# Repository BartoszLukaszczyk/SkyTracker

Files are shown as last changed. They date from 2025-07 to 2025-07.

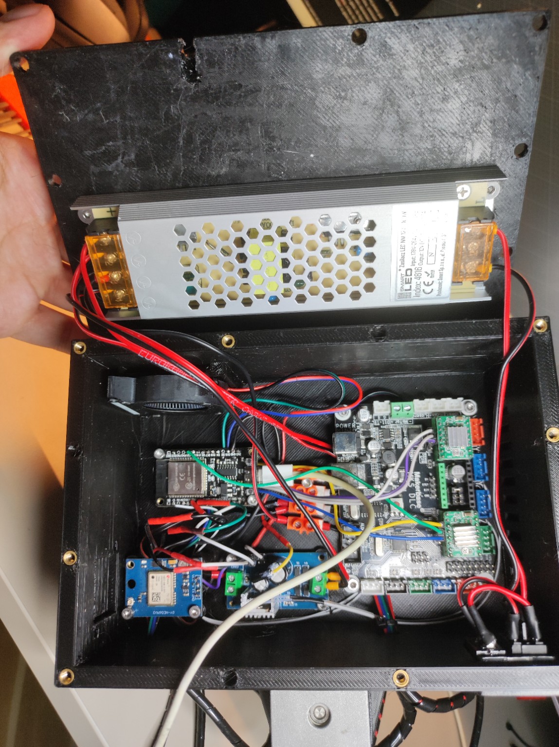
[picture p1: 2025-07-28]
images/electronics overview.jpg

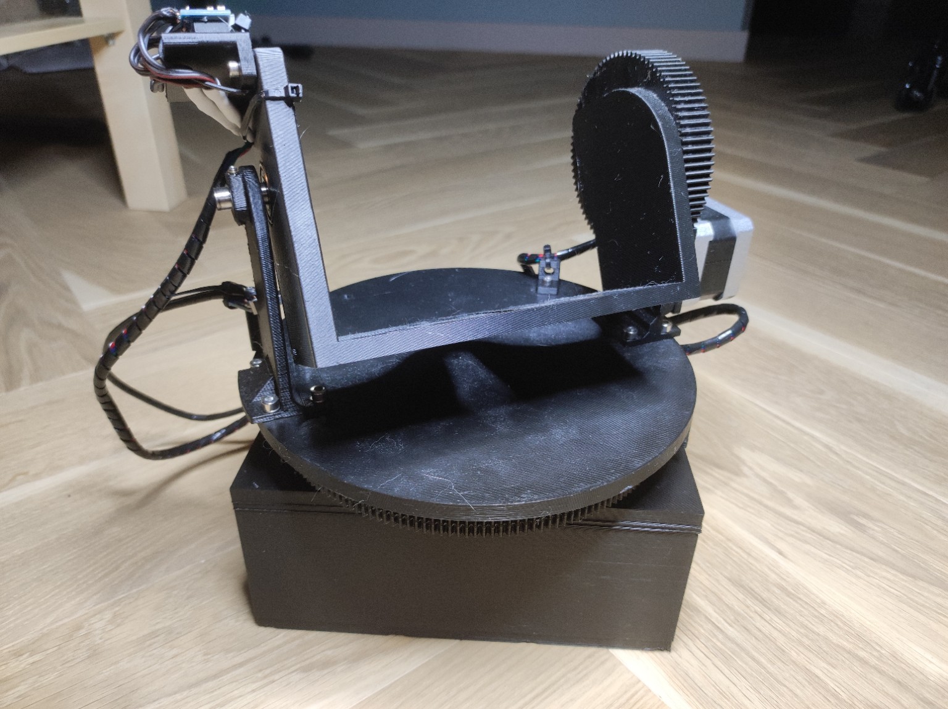
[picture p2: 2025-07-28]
images/Device (1).jpg

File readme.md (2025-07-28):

# GIGA Projekt: Portable Alt-Az Sky Tracker

Author: **Bartosz Łukaszczyk**\
License: **MIT License**

---

## About the Project

GIGA Projekt is a portable, motorized Alt-Az tracking platform designed to follow astronomical objects in real time. It uses an ESP32 microcontroller to control two stepper motors (Pan and Tilt axes) based on celestial coordinates downloaded from the NASA JPL Horizons API. The device is calibrated via hardware limit switches and can be controlled using a dedicated Qt-based Android app via Bluetooth.

This project is fully open-source, including hardware, 3D models, and software.

---

## Key Features

- Bluetooth communication between Android and ESP32
- JPL Horizons integration (Sun, Moon, Planets)
- Spherical interpolation for smooth movement every 4 seconds
- Live tracking with correction support
- Manual control mode
- Homing procedure using limit switches

---

## Mechanical Design

- Pan axis shaft is made of metal (printed one was too fragile)
- Gear ratio Pan: **14/180**, Tilt: **14/84**
- Tilt cradle mounted on smooth shafts and ball bearings
- M3 and M4 heat-set threaded inserts used throughout
- STL and F3D files are available in the `models/` directory for easy customization
- All required parts are listed in `docs/BOM.pdf`

### Mechanical Advice

- Insert a piece of metal sheet under the Pan stepper motor mounting screws to prevent deformation of the printed base plate

---

## Electronics

- ESP32 DevKit, communicating over BLE
- MKS DLC V2 + A4988 drivers
- IMU (MPU-6050) and compass (QMC5883L)
- Limit switches for both axes
- 12V 8A power supply

Optional modules (GPS and fan with thermistor) were initially planned but removed during development:

The GPS module caused reliability issues and was replaced by the smartphone's internal GPS.

The fan, controlled by a thermistor, was counterproductive — it was the main source of heat buildup, especially affecting the buck converter. Removing it simplified the system and improved thermal stability.

Block diagram and wiring diagrams are included in `docs/`.

---

## Software Overview

### Android App

- Written in C++ using **Qt Creator 6.9.1**, built with **qmake**
- Requires pairing with ESP32 via Android system Bluetooth settings
- Device must be selected from **paired devices** inside the app
- ⚠️ “Connected” message may appear even if pairing fails – verify manually

### ESP32 Firmware
- Written in C++ using **Arduino IDE**
- Receives commands from Android app over Bluetooth serial

---

### 🎮 Manual Control

- Single tap = 5 motor steps
- Hold = continuous smooth motion

---

### 🧭 Homing / Calibration

1. Move both axes toward endstops
2. Back off 100 steps
3. Read orientation from IMU + compass
4. Set virtual position to **180° Azimuth / 45° Elevation**

This is the reference position for tracking.

---

### 🌌 Object Tracking

1. User selects object from list
2. App gets phone's GPS location
3. Ephemerides fetched via **JPL Horizons API**
4. 1-hour dataset downloaded (1-minute resolution)
5. Az/El positions calculated, corrected for Earth's rotation
6. **Spherical interpolation** every 4 seconds
7. Motor steps computed based on current gear ratios
8. Motion starts between minute 1–2 after object selection

- Manual adjustments are allowed during tracking
- Phone must remain connected via Bluetooth
- Power-saving settings may require app to stay foregrounded

---

## Project Structure

```
gigaprojekt/
├── src/
│   ├── Qt/          # Qt Android application
│   └── ESP/         # ESP32 firmware
├── models/          # STL, F3D files for 3D printing
├── docs/            # BOM, schematics, diagrams
├── images/          # Device photos
├── README.md
├── LICENSE          # MIT License
└── .gitignore
```

---

## How to Build

### Qt App (Android)

1. Open `src/Qt/gigaprojekt.pro` in Qt Creator
2. Configure Android kit with qmake
3. Build & deploy to paired Android phone
4. Pair the ESP32 from Android system settings

### ESP32 Firmware

1. Open `src/ESP/main.ino` in Arduino IDE
2. Select ESP32 DevKit board
3. Install required libraries (`Wire`, `MPU6050`, etc.)
4. Upload firmware

---

## Contact

For questions or contributions, feel free to open an issue or pull request.

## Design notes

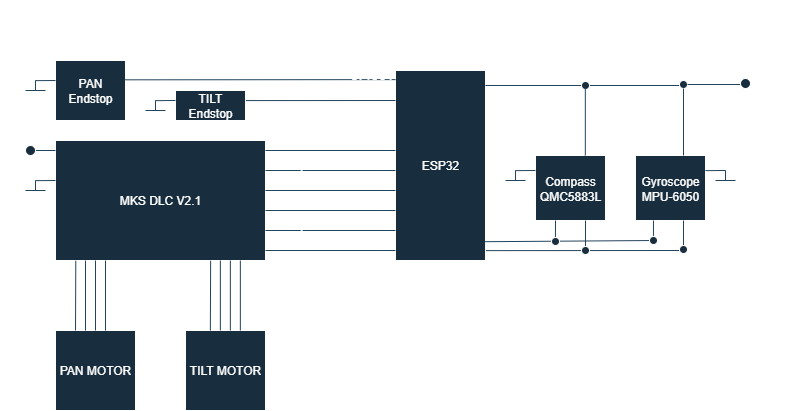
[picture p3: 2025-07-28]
docs/Block_Diagram.png

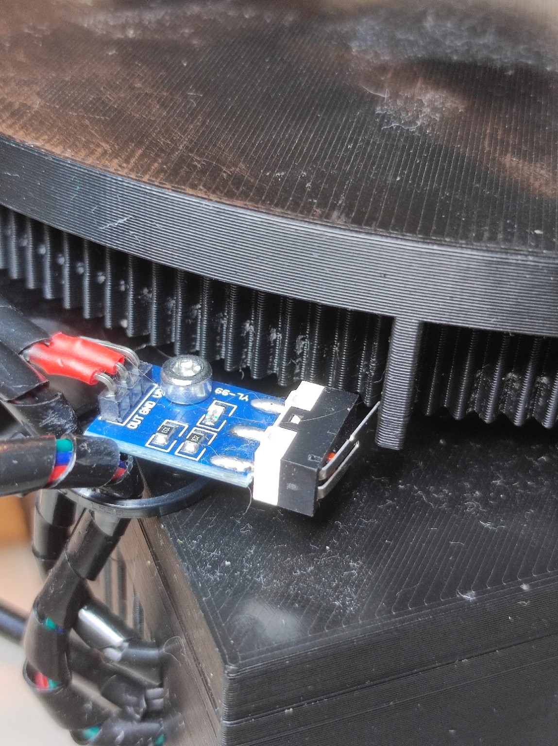
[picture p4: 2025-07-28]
images/Pan axis (1).jpg

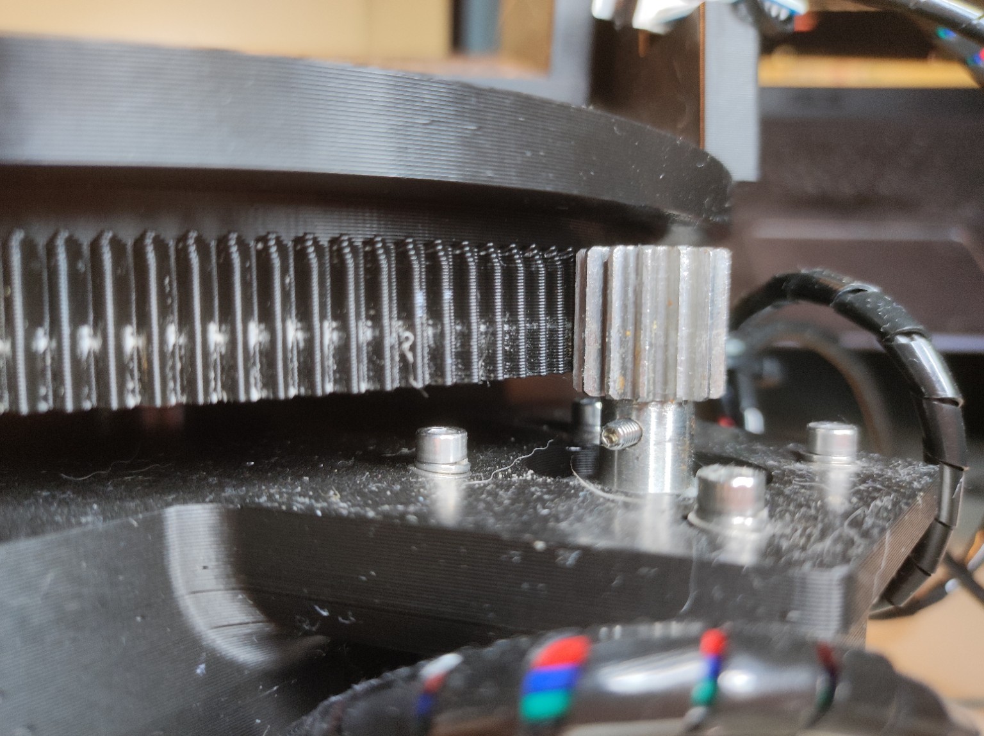
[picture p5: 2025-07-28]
images/Pan axis (4).jpg

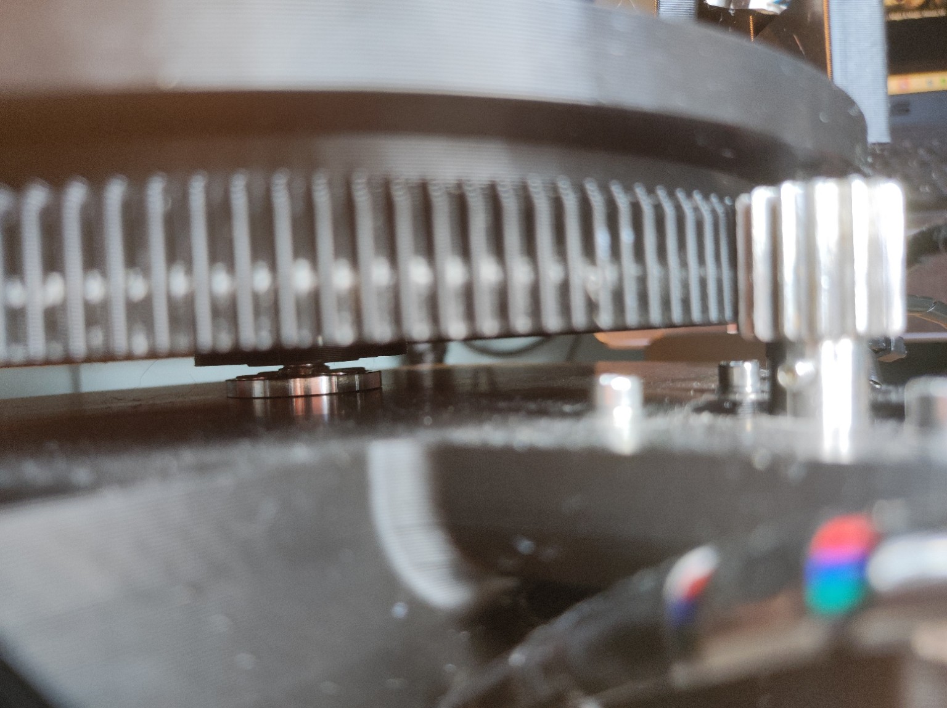
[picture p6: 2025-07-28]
images/Pan axis (3).jpg

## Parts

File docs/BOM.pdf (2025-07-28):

Component | Qty | Descripon
Bolt 8 mm | 2 | Ø8 × 80 mm, stainless steel
Ball bearing 8×22×7 | 2 | 608 ZZ / 608 RS
Tilt gear (small) | 1 | Module 1, Z14, Ø16 mm,
Pan gear (small) | 1 | Module 1, Z14, Ø16 mm,
NEMA 17 stepper motor (Pan) | 1 | 42×42 mm, 5 mm sha, 12 V, ~1.5–2 A
NEMA 17 stepper motor (Tilt) | 1 | 42×42 mm, 5 mm sha, 12 V, ~1.5–2 A
A4988 driver | 2 | included with MKS DLC V2.1
MKS DLC V2.1 | 1 | Atmega328P + stepper motor drivers
ESP32 DevKit (ESP-WROOM-32) | 1 | USB-C 5V, WiFi, BLE, GPIO, I2C, UART
IMU MPU-6050 GY-521 | 1 | I2C, 3.3V
Compass QMC5883L GY-271 | 1 | I2C, 3.3V
Buck converter 12V→5V | 1 | 3A, step-down
Power supply 12V 8A | 1 | 100W, AC 100–240V → DC 12V
Power cable | 2 m | AC mains cable
Cable (0.75 mm²) | 2 m | For power connecons
Wires (0.25 mm²) | 5 m | For signal connecons
USB-C cable (ESP32) | 1 m | For programming and power
bolt M3 (DIN913) | 2
bolt M3x10 (DIN912) | 8
bolt M3x12 (DIN912) | 4
bolt M3x6 (DIN7991) | 11
bolt M3x6 (DIN912) | 18
bolt M3x8 (DIN912) | 10
bolt M4x10 (DIN912) | 8
bolt M4x12 (DIN7991) | 12
bolt M4x8 (DIN7991) | 8
insert M3 | 42
insert M4 | 28
spring washer M3 (DIN127) | 4
spring washer M4 (DIN127) | 8
washer M3 (DIN125) | 4
washer M4 (DIN125) | 8

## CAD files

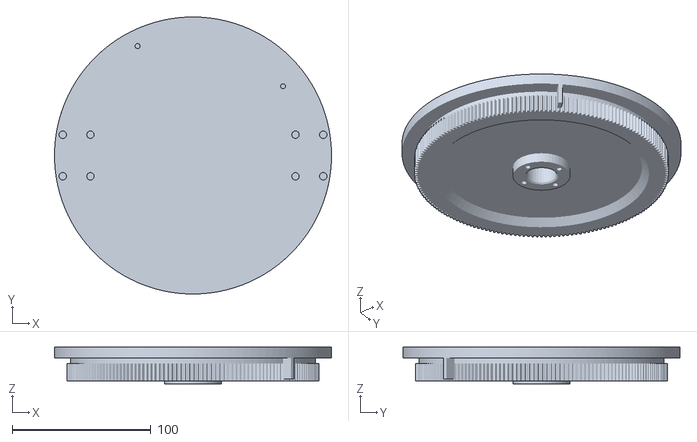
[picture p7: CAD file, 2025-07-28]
models/STL files/Pan axis gear.stl
200.0 x 200.0 x 26.7

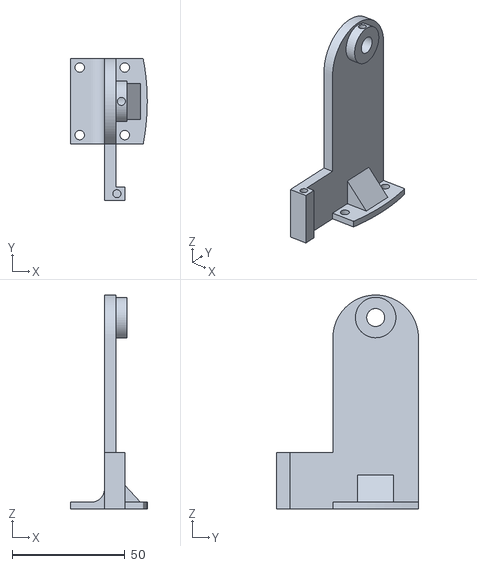
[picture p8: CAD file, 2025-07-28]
models/STL files/Left handle.stl
34.0 x 63.0 x 95.0

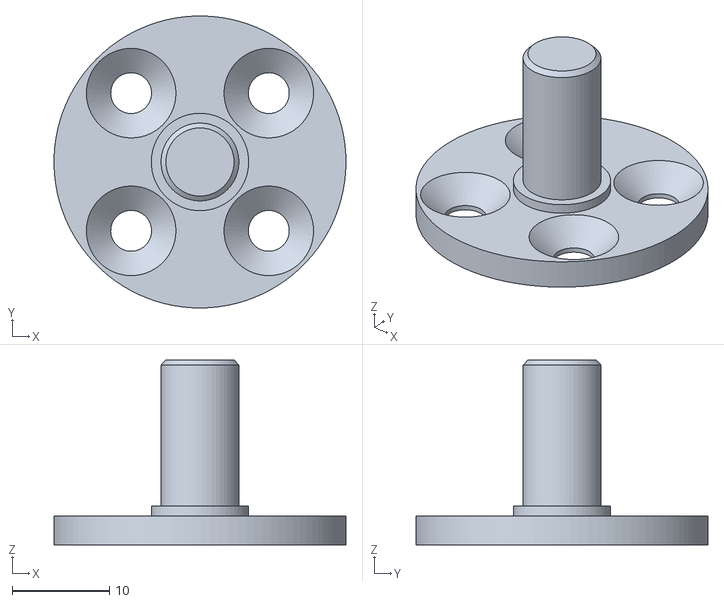
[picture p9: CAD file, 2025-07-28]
models/STL files/Pan axis shaft.stl
30.0 x 30.0 x 19.0

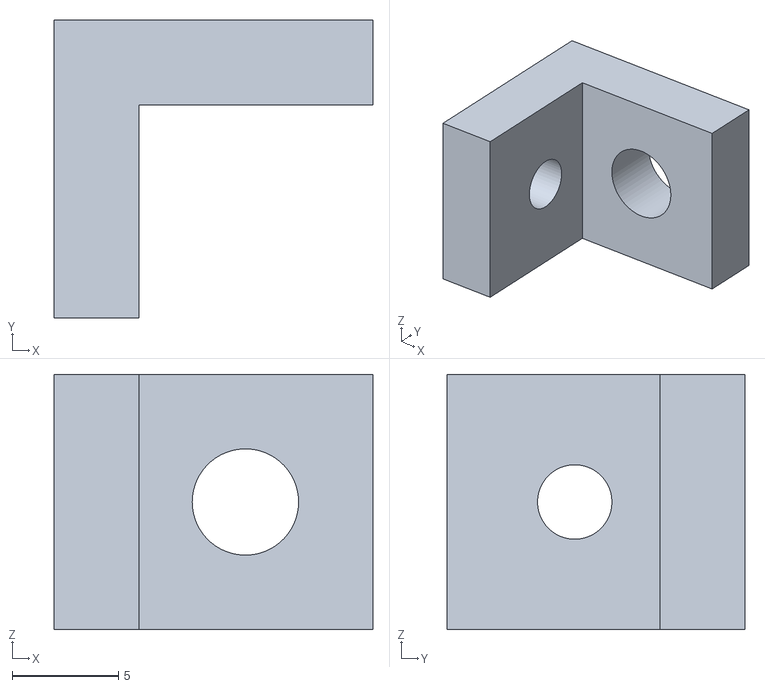
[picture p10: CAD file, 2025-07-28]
models/STL files/Wires handle.stl
15.0 x 14.0 x 12.0

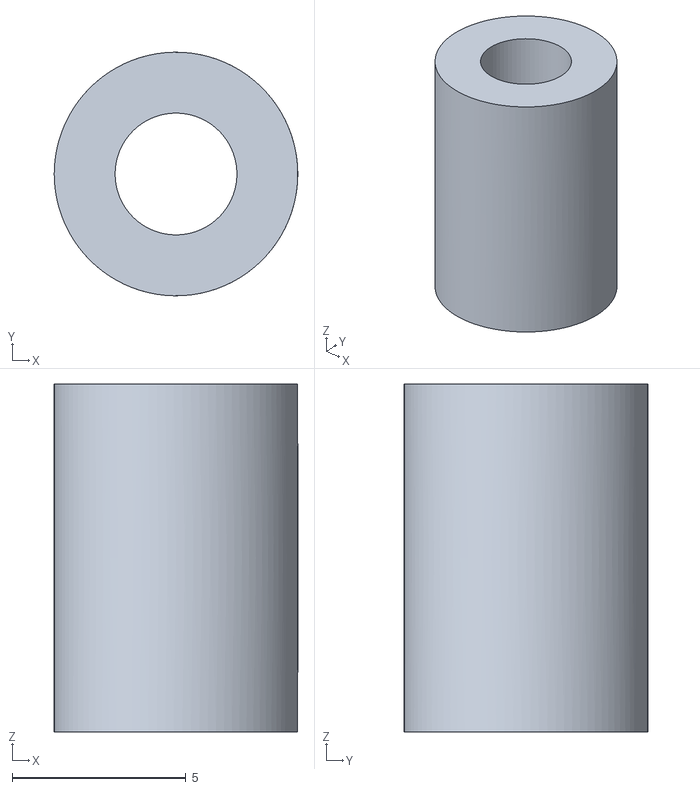
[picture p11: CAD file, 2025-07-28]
models/STL files/Endstop spacer.stl
7.00 x 7.00 x 10.0

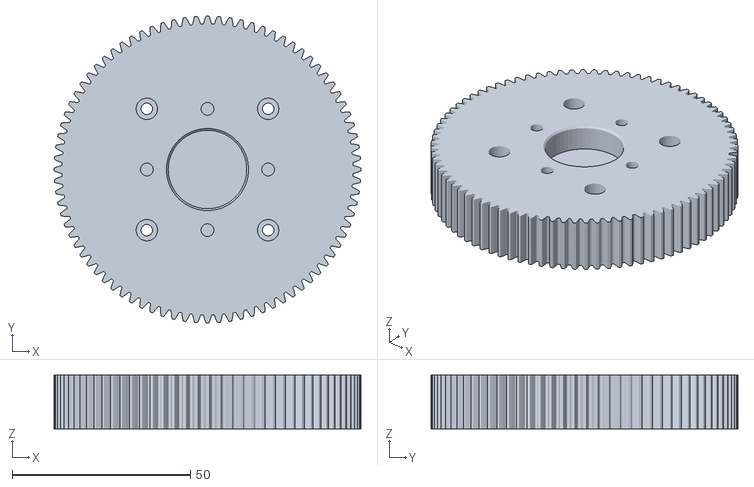
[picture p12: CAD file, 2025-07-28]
models/STL files/Tilit axis gear.stl
86.0 x 86.0 x 15.0

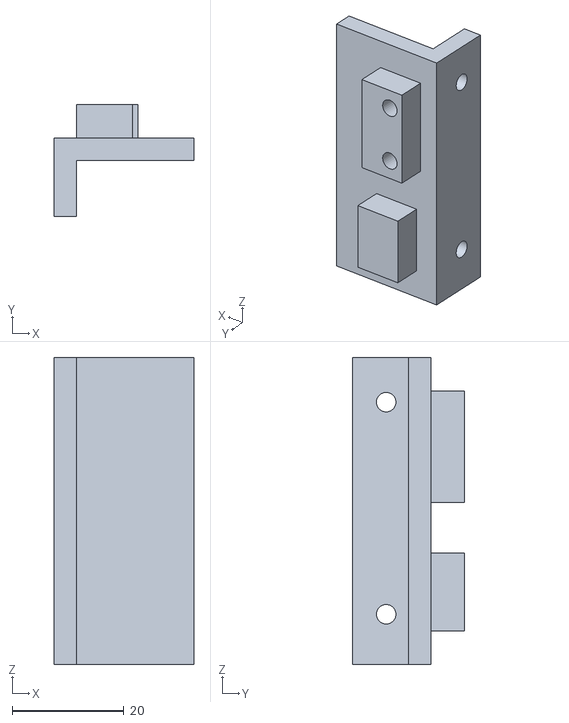
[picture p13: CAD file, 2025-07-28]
models/STL files/Sensors mounting.stl
25.0 x 20.0 x 55.0

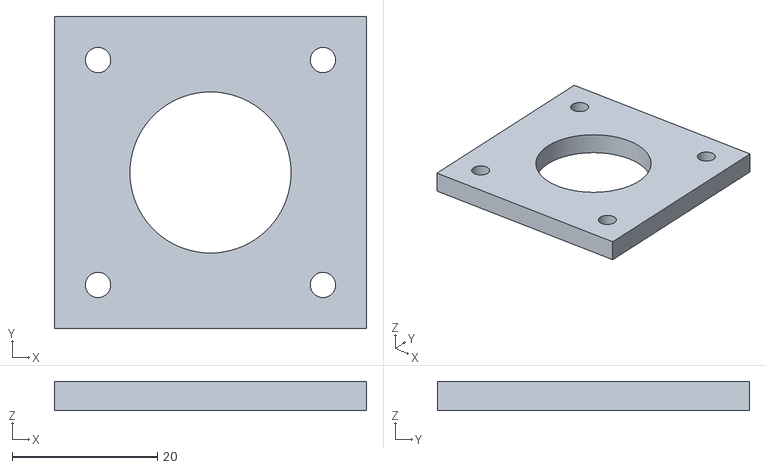
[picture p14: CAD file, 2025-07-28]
models/STL files/Tilt motor spacer.stl
43.0 x 43.0 x 4.00

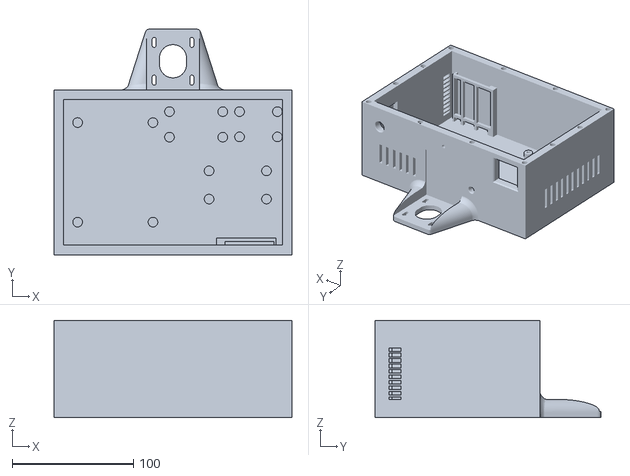
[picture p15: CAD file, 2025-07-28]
models/STL files/Base.stl
196.0 x 186.0 x 80.0

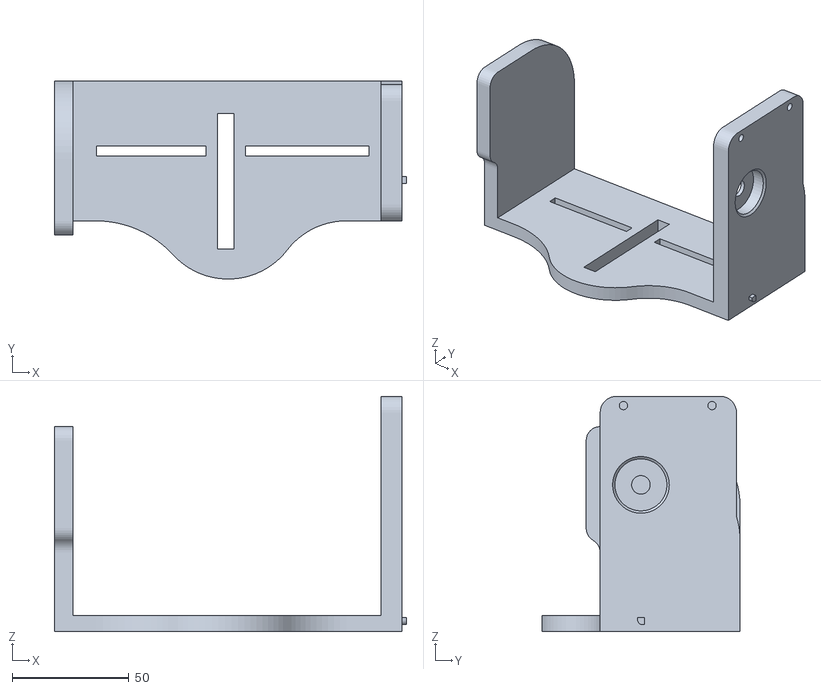
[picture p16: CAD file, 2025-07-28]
models/STL files/Tilt.stl
151.0 x 84.9 x 101.0

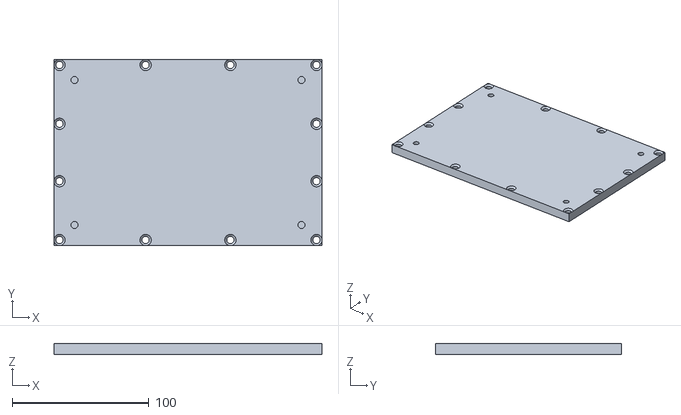
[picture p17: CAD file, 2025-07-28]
models/STL files/Base cover.stl
196.0 x 136.0 x 8.00

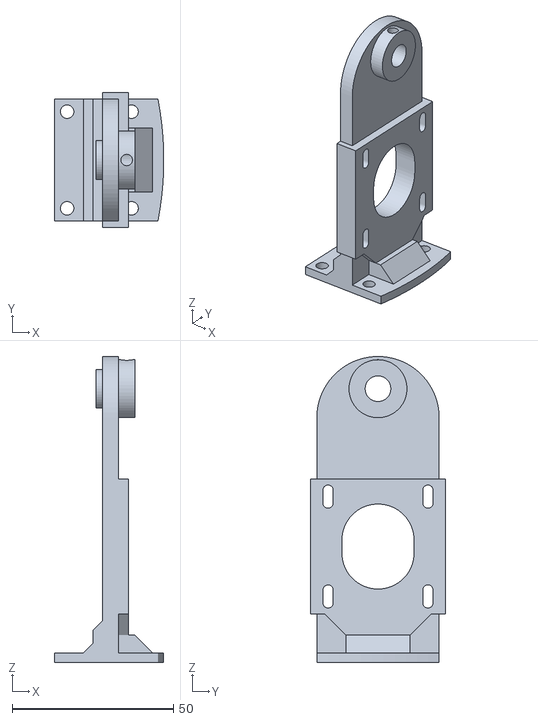
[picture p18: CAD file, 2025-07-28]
models/STL files/Right handle.stl
34.0 x 42.0 x 95.0

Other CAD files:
models/f3d files/Base cover.f3d
models/f3d files/Base.f3d
models/f3d files/Cradle.f3d
models/f3d files/Endstop spacer.f3d
models/f3d files/Left handle.f3d
models/f3d files/Pan axis shaft.f3d
models/f3d files/Right handle.f3d
models/f3d files/Sensors mounting.f3d
models/f3d files/Tilt motor spacer.f3d
models/f3d files/Wires handle.f3d

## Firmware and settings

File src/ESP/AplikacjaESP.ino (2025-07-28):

#include <Arduino.h>
#include <Wire.h>
#include <Adafruit_Sensor.h>
#include <Adafruit_HMC5883_U.h>
#include <MPU6050_light.h>
#include <AccelStepper.h>
#include <BluetoothSerial.h>
#include <FS.h>
#include <SPIFFS.h>

#include "HomingAdvanced.h"
#include "SphericalTracker.h"

// --- I2C pins ---
#define SDA_PIN         25
#define SCL_PIN         26

// --- Motor pins ---
#define PAN_STEP_PIN    18
#define PAN_DIR_PIN     19
#define PAN_ENABLE_PIN  5
#define PAN_ENDSTOP_PIN 32

#define TILT_STEP_PIN    21
#define TILT_DIR_PIN     22
#define TILT_ENABLE_PIN  4
#define TILT_ENDSTOP_PIN 33

// --- Mechanical parameters ---
const float STEP_ANGLE_DEG  = 1.8;
const int   MICROSTEPS      = 8;
const float GEAR_MOTOR      = 14.0;
const float GEAR_AXIS_PAN   = 180.0;
const float GEAR_AXIS_TILT  = 84.0;

const float gearRatioPan    = GEAR_MOTOR / GEAR_AXIS_PAN;
const float gearRatioTilt   = GEAR_MOTOR / GEAR_AXIS_TILT;

const float degPerMicroPan  = (STEP_ANGLE_DEG/MICROSTEPS) * gearRatioPan;
const float degPerMicroTilt = (STEP_ANGLE_DEG/MICROSTEPS) * gearRatioTilt;

// --- Homing params ---
const float HOME_SPEED    = 500.0;
const long  BACKOFF       = 100;

// --- Sensors & Steppers ---
Adafruit_HMC5883_Unified mag(12345);
MPU6050                    mpu(Wire);
AccelStepper               panStp(AccelStepper::DRIVER, PAN_STEP_PIN, PAN_DIR_PIN);
AccelStepper               tiltStp(AccelStepper::DRIVER, TILT_STEP_PIN, TILT_DIR_PIN);

bool waitingForPrep = false;
bool prepExecuted = false;

HomingAdvanced homing(
  panStp, PAN_ENDSTOP_PIN, PAN_ENABLE_PIN, PAN_DIR_PIN, PAN_STEP_PIN,
  tiltStp, TILT_ENDSTOP_PIN, TILT_ENABLE_PIN, TILT_DIR_PIN, TILT_STEP_PIN,
  degPerMicroPan, degPerMicroTilt,
  mag, mpu,
  HOME_SPEED, BACKOFF
);

// --- Bluetooth ---
BluetoothSerial SerialBT;
const char*      btName    = "ESP32-Tracker";
const char*      btPin     = "1234";
bool             wasClient = false;

// --- Trajectory buffer ---
constexpr int MAX_POINTS = 1024;
static TrackPoint trajBuf[MAX_POINTS];
static uint16_t   expectPts = 0, recvPts = 0;
static uint32_t   T0_unix   = 0;
static bool       inRxTraj  = false;

// --- Tracker instance ---
SphericalTracker tracker(panStp, tiltStp, degPerMicroPan, degPerMicroTilt, MAX_POINTS);

// --- Manual drive flags & speeds ---
bool  movingPan  = false;
bool  movingTilt = false;
float speedPan   = 0;
float speedTilt  = 0;


void processCmd(const String &raw, bool viaBT) {
  String cmd = raw;
  cmd.trim();

  if (cmd == "HOME") {
    homing.homeAll();
    if (viaBT) SerialBT.println("HOMED"); else Serial.println("HOMED");
  }
  else if (cmd == "PING") {
    if (viaBT) SerialBT.println("PONG"); else Serial.println("PONG");
  }
  else if (cmd == "BREAK") {
    // tracker.stop();
    if (viaBT) SerialBT.println("TRACK_STOPPED"); else Serial.println("TRACK_STOPPED");
  }
  // Single-step manual
  else if (cmd == "UP") {
    tiltStp.enableOutputs();
    tiltStp.move(-5);
    tiltStp.runToPosition();
    tiltStp.disableOutputs();
    if (viaBT) SerialBT.println("OK"); else Serial.println("OK");
  }
  else if (cmd == "DOWN") {
    tiltStp.enableOutputs();
    tiltStp.move(+5);
    tiltStp.runToPosition();
    tiltStp.disableOutputs();
    if (viaBT) SerialBT.println("OK"); else Serial.println("OK");
  }
  else if (cmd == "LEFT") {
    panStp.enableOutputs();
    panStp.move(-5);
    panStp.runToPosition();
    panStp.disableOutputs();
    if (viaBT) SerialBT.println("OK"); else Serial.println("OK");
  }
  else if (cmd == "RIGHT") {
    panStp.enableOutputs();
    panStp.move(+5);
    panStp.runToPosition();
    panStp.disableOutputs();
    if (viaBT) SerialBT.println("OK"); else Serial.println("OK");
  }
  // Continuous manual start
  else if (cmd == "UP_START") {
    movingTilt = true;
    speedTilt  = -500;
    tiltStp.enableOutputs();
    tiltStp.setSpeed(speedTilt);
  }
  else if (cmd == "DOWN_START") {
    movingTilt = true;
    speedTilt  = +500;
    tiltStp.enableOutputs();
    tiltStp.setSpeed(speedTilt);
  }
  else if (cmd == "LEFT_START") {
    movingPan  = true;
    speedPan   = -1000;
    panStp.enableOutputs();
    panStp.setSpeed(speedPan);
  }
  else if (cmd == "RIGHT_START") {
    movingPan  = true;
    speedPan   = +1000;
    panStp.enableOutputs();
    panStp.setSpeed(speedPan);
  }else if (cmd == "FUP") {
    tiltStp.enableOutputs();
    tiltStp.move(-1);
    tiltStp.runToPosition();
    tiltStp.disableOutputs();
    if (viaBT) SerialBT.println("OK"); else Serial.println("OK");
  }
  else if (cmd == "FDOWN") {
    tiltStp.enableOutputs();
    tiltStp.move(+1);
    tiltStp.runToPosition();
    tiltStp.disableOutputs();
    if (viaBT) SerialBT.println("OK"); else Serial.println("OK");
  }
  else if (cmd == "FLEFT") {
    panStp.enableOutputs();
    panStp.move(-1);
    panStp.runToPosition();
    panStp.disableOutputs();
    if (viaBT) SerialBT.println("OK"); else Serial.println("OK");
  }
  else if (cmd == "FRIGHT") {
    panStp.enableOutputs();
    panStp.move(+1);
    panStp.runToPosition();
    panStp.disableOutputs();
    if (viaBT) SerialBT.println("OK"); else Serial.println("OK");
  }
  else if (cmd == "STOP") {
    movingPan = movingTilt = false;
    panStp.setSpeed(0);
    tiltStp.setSpeed(0);
    if (viaBT) SerialBT.println("MAN_STOPPED"); else Serial.println("MAN_STOPPED");
  }
  else if (cmd == "PREP") {
    waitingForPrep = true;
    prepExecuted = false;
    if (viaBT) SerialBT.println("PREP_OK"); else Serial.println("PREP_OK");
  }
  else if (waitingForPrep && !prepExecuted && cmd.startsWith("STEP ")) {
    prepExecuted = true;
    waitingForPrep = false;
    int space1 = cmd.indexOf(' ');
    int space2 = cmd.indexOf(' ', space1 + 1);

    if (space1 == -1 || space2 == -1) {
      if (viaBT) SerialBT.println("PREP_BAD_FORMAT");
      else       Serial.println("PREP_BAD_FORMAT");
      return;
    }

    int deltaPan  = cmd.substring(space1 + 1, space2).toInt();
    int deltaTilt = cmd.substring(space2 + 1).toInt();

    Serial.printf("[ESP] PREP Step: Pan=%d, Tilt=%d\n", deltaPan, deltaTilt);

    panStp.enableOutputs();
    tiltStp.enableOutputs();
    panStp.move(deltaPan/2);
    tiltStp.move(-deltaTilt/2);
    while (panStp.isRunning() || tiltStp.isRunning()) {
      panStp.run();
      tiltStp.run();
    }
    panStp.disableOutputs();
    tiltStp.disableOutputs();

    if (viaBT) SerialBT.println("PREP_DONE"); else Serial.println("PREP_DONE");
  }
  else if (cmd.startsWith("STEP ")) {
    Serial.println("[ESP] Rejected repeated STEP");
  }
  else {
    if (viaBT) SerialBT.printf("UNKNOWN:%s\n", cmd.c_str());
    else        Serial.printf("UNKNOWN:%s\n", cmd.c_str());
  }
}

void setup() {
  Serial.begin(115200);
  Wire.begin(SDA_PIN, SCL_PIN);
  delay(200);

  // Bluetooth init
  SerialBT.begin(btName, true);
  SerialBT.setPin(btPin, strlen(btPin));
  SerialBT.enableSSP();
  Serial.printf("BT \"%s\" PIN %s\n", btName, btPin);

  // Homing & steppers config
  homing.begin();
  panStp.setMaxSpeed(4000);
  panStp.setAcceleration(4000);
  tiltStp.setMaxSpeed(2000);
  tiltStp.setAcceleration(1000);
}

void loop() {
  // BT client tracking
  bool client = SerialBT.hasClient();
  if (client && !wasClient) {
    Serial.println("CLIENT_CONNECTED");
    SerialBT.println("CLIENT_CONNECTED");
  }
  wasClient = client;

  if (client && SerialBT.available()) {
    size_t avail = SerialBT.available();
    String line = SerialBT.readStringUntil('\n');
    line.trim();
    Serial.printf("[ESP] Recived raw: '%s'\n", line.c_str());
    processCmd(line, true);
  }

  // Read USB
  if (Serial.available()) {
    String line = Serial.readStringUntil('\n');
    processCmd(line, false);
  }
  // Read BT
  if (client && SerialBT.available()) {
    String line = SerialBT.readStringUntil('\n');
    processCmd(line, true);
  }

  uint32_t nowSec = uint32_t(time(nullptr));

  if (tracker.isTracking()) {
    // automatic tracking
    tracker.update(nowSec);
    tracker.runSteppers();
  } else {
    // manual continuous
    if (movingPan)   panStp.runSpeed(); else panStp.disableOutputs();
    if (movingTilt)  tiltStp.runSpeed(); else tiltStp.disableOutputs();
  }

  delay(10);
}

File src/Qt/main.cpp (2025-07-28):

#include "mainwindow.h"
#include <QSslSocket>
#include <QSslCertificate>
#include <QSslConfiguration>

#include <QApplication>

int main(int argc, char *argv[])
{
    qDebug() << "SSL support:" << QSslSocket::supportsSsl();
    // → true
    qDebug() << "SSL build version:" << QSslSocket::sslLibraryBuildVersionString();
    // → np. “OpenSSL 1.1.1k …”

    QApplication a(argc, argv);

    auto caCerts = QSslCertificate::fromPath(":/certs/cacert.pem", QSsl::Pem);
    qDebug() << "Loaded CA certificates:" << caCerts.count();
    if (caCerts.isEmpty()) {
        qWarning() << "Failed to load CACERT.PEM!";
    } else {
        // Add certificates to the default SSL configuration
        QSslConfiguration cfg = QSslConfiguration::defaultConfiguration();
        cfg.setCaCertificates(caCerts);
        QSslConfiguration::setDefaultConfiguration(cfg);
        qDebug() << "CACERT.PEM successfully loaded from resources.";
    }
    MainWindow w;
    w.show();
    return a.exec();
}

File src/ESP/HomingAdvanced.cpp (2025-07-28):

#include "HomingAdvanced.h"
#include <Arduino.h>
#include <Wire.h>  // inicjalizację usuniemy stąd

HomingAdvanced::HomingAdvanced(
    AccelStepper& panStp, uint8_t panEndPin, uint8_t panEn, uint8_t panDir, uint8_t panStep,
    AccelStepper& tiltStp, uint8_t tiltEndPin, uint8_t tiltEn, uint8_t tiltDir, uint8_t tiltStep,
    float degPerMicroPan, float degPerMicroTilt,
    Adafruit_HMC5883_Unified& magSensor, MPU6050& mpuSensor,
    float homeSpeed, long backoffSteps
  )
  : panStepper(panStp)
  , panEndstopPin(panEndPin)
  , panEnablePin(panEn)
  , panDirPin(panDir)
  , panStepPin(panStep)
  , tiltStepper(tiltStp)
  , tiltEndstopPin(tiltEndPin)
  , tiltEnablePin(tiltEn)
  , tiltDirPin(tiltDir)
  , tiltStepPin(tiltStep)
  , degPerStepPan(degPerMicroPan)
  , degPerStepTilt(degPerMicroTilt)
  , mag(magSensor)
  , mpu(mpuSensor)
  , speedHome(homeSpeed)
  , backoff(backoffSteps)
{}

void HomingAdvanced::begin() {
  // I²C-inicjalizację wykonaj w szkicu:
  // Wire.begin(SDA_PIN, SCL_PIN);
  Wire.setClock(100000);

  // Sensory
  if (!mag.begin()) {
    Serial.println("Error: HMC5883L not found");
    while (1);
  }
  if (mpu.begin() != 0) {
    Serial.println("Error: MPU6050 init failed");
    while (1);
  }
  mpu.calcGyroOffsets();
  Serial.println("Sensors initialized");

  // Krańcówki
  pinMode(panEndstopPin, INPUT_PULLUP);
  pinMode(tiltEndstopPin, INPUT_PULLUP);

  // Driver-enable
  pinMode(panEnablePin, OUTPUT);
  pinMode(tiltEnablePin, OUTPUT);
  digitalWrite(panEnablePin, LOW);
  digitalWrite(tiltEnablePin, LOW);

  // Steppery
  panStepper.setMaxSpeed(speedHome);
  panStepper.setAcceleration(speedHome);
  tiltStepper.setMaxSpeed(speedHome);
  tiltStepper.setAcceleration(speedHome);
}

void HomingAdvanced::homeAll() {
  Serial.println("=== Starting full homing ===");
  homeAxis(panStepper, panEndstopPin);
  Serial.println("Pan homed at 0");
  homeAxis(tiltStepper, tiltEndstopPin);
  Serial.println("Tilt homed at 0");
  backoffBoth();
  Serial.println("Repositioning to 180° azimuth & 45° elevation...");
  reposition(180.0f, 45.0f);
  Serial.println("Repositioning done");
  Serial.println("Drivers disabled – full homing complete");
}

void HomingAdvanced::homeAxis(AccelStepper& stp, uint8_t endPin) {
  stp.setSpeed(speedHome);
  while (digitalRead(endPin) == HIGH) {
    stp.runSpeed();
  }
  stp.setCurrentPosition(0);
}

void HomingAdvanced::backoffBoth() {
  Serial.printf("Backoff %ld steps\n", backoff);
  panStepper.move(-backoff);
  tiltStepper.move(-backoff);
  panStepper.runToPosition();
  tiltStepper.runToPosition();
  Serial.println("Drivers disabled");
}

void HomingAdvanced::readOrientation(float &azDeg, float &elDeg) {
  sensors_event_t magEvent;
  mag.getEvent(&magEvent);
  mpu.update();
  float ax = mpu.getAccX(), ay = mpu.getAccY(), az = mpu.getAccZ();

  float heading = atan2(magEvent.magnetic.y, magEvent.magnetic.x) * 180.0 / M_PI;
  if (heading < 0) heading += 360.0;
  azDeg = heading;

  elDeg = atan2(-ax, sqrt(ay*ay + az*az)) * 180.0 / M_PI;
}

void HomingAdvanced::moveAxis(uint8_t dirPin, uint8_t stepPin, float deltaDeg, float degPerMicrostep) {
  long steps = lround(abs(deltaDeg) / degPerMicrostep);
  digitalWrite(dirPin, (deltaDeg >= 0) ? HIGH : LOW);
  for (long i = 0; i < steps; ++i) {
    digitalWrite(stepPin, HIGH);
    delayMicroseconds(500);
    digitalWrite(stepPin, LOW);
    delayMicroseconds(500);
  }
}

void HomingAdvanced::reposition(float targetAz, float targetEl) {
  float currAz, currEl;
  readOrientation(currAz, currEl);

  float rawAz = fmod(targetAz - currAz + 360.0, 360.0);
  float deltaAz = (rawAz > 0) ? rawAz - 360.0 : rawAz;
  float deltaEl = targetEl - currEl;

  Serial.printf("⏩ Reposition: AZ %.2f°, EL %.2f°\n", deltaAz, deltaEl);
  moveAxis(panDirPin,  panStepPin,  deltaAz, degPerStepPan);
  moveAxis(tiltDirPin, tiltStepPin, -deltaEl, degPerStepTilt);
}
